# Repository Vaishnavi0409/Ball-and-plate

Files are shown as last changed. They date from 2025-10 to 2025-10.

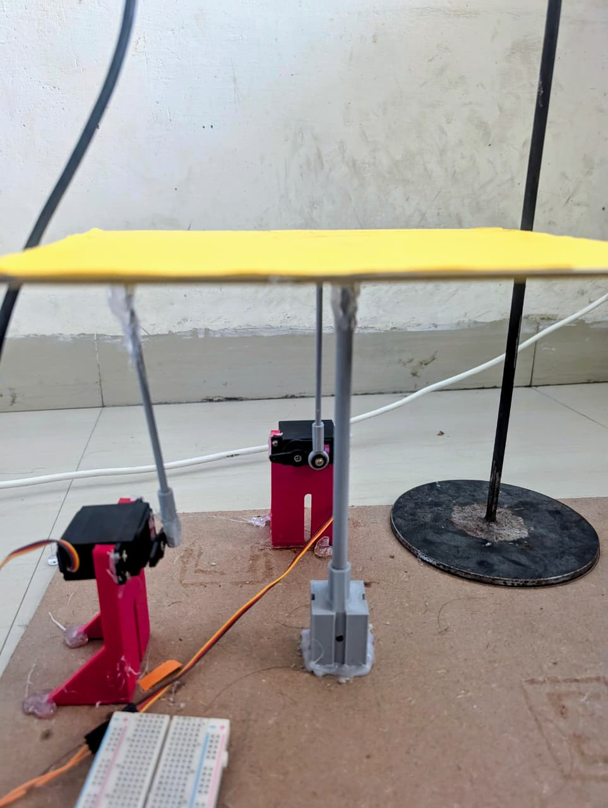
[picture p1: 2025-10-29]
images_video/system_image.jpeg

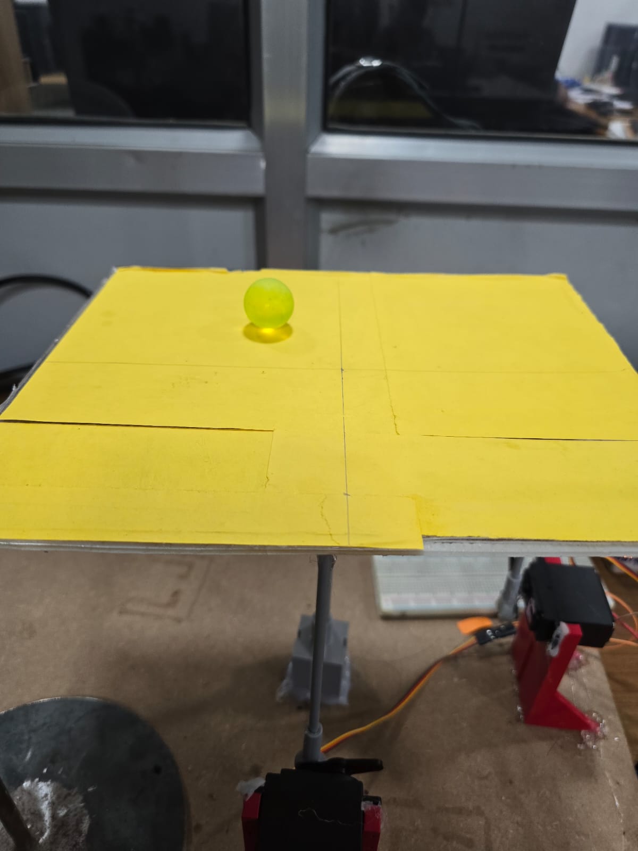
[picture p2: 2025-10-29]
images_video/system image.jpeg

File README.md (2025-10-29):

# Ball and Plate Balancing System
This project is a real-time, closed-loop control system that uses computer vision to balance a ball on a 2-axis tilting plate. The system can also guide the ball to follow dynamic paths, such as a circle or an 8-shape, all controlled via a custom Python GUI.

Initial simulations for the control logic were performed in MATLAB & Simulink (see MATLAB_Simulink folder). The physical model was constructed using custom 3D-printed components.

🎥 Demonstration
The video below shows the ball successfully tracking a circular setpoint (red dot) generated by the GUI.

(Pro Tip: Convert your circle_video.mp4 to a demo.gif to embed it here. You can't embed videos directly, but a GIF will auto-play.)

System Demo

⚙️ Technical Workflow
The system operates in a continuous "see-think-act" loop:

1. Plate Detection (Region of Interest)
To focus processing power and eliminate noise, the system first isolates the plate:

Edge Detection: A first pass is done to identify rectangular shapes in the camera feed.

Color Filtering: The selection is refined by searching for a specific yellow color, locking onto the plate.

Cropping: The video feed is then trimmed to the plate's dimensions (with a 2-pixel offset), creating a precise Region of Interest (ROI).

2. Ball Detection (3-Filter Pipeline)
A robust, 3-stage filter is used to accurately detect the ball within the ROI:

Hough Circle Transform: Detects all circular objects.

Color Filter: Isolates the objects that match the ball's specific color.

Shape & Size Validation: A final filter ensures the object is perfectly round and within the expected size range, rejecting any "absurd" circles or visual noise.

3. PID Control Loop
Error Calculation: Once the ball's (x,y) position is found, the system calculates the error vector (distance) between the ball and the target setpoint (the blue dot).

PID Controller: This error is fed into a PID controller. The controller's output (the corrective tilt angles) is calculated based on the gains (Kpx, Kpy, Kix, Kiy, Kdx, Kdy) set in the GUI.

Serial Communication: The calculated X and Y tilt angles are sent to the Arduino via serial communication at a fixed baud rate.

4. Hardware Actuation
The Arduino, running the final_arduino.py logic, receives the target angles.

It translates these angles into the precise angular positions required for the two servo motors.

The servos tilt the plate, which moves the ball, thus closing the loop.

🚀 Key Features
Real-time PID Control: All P, I, and D gains for both X and Y axes can be tuned live via the GUI for optimal performance.

Dynamic Path Following: Includes modes for "Circle Movement" and "8-Shape Movement," where the setpoint moves and the ball dynamically follows.

Robust 2-Stage Plate Detection: Uses both shape and color to lock onto the plate and create a processing-efficient ROI.

High-Accuracy 3-Filter Ball Tracking: Drastically reduces false positives by filtering for shape, color, and size.

3D-Printed Hardware: The majority of the mechanical components are 3D-printed.

Initial Simulation: Includes MATLAB/Simulink files for reference, showing the initial design and testing of the control theory.

📂 File Structure
🛠️ Hardware & Software
Required Hardware
Arduino (or compatible microcontroller)

2x Servo Motors

USB Webcam

3D-Printed components

A yellow-colored plate

A distinctly colored ball

Software Setup
Python Environment: This project requires Python 3. You can install the necessary libraries using pip:

Arduino Setup:

Upload the code from final_arduino.py to your Arduino board.

Ensure the baud rate in the script matches the one set in interface.py.

▶️ How to Run
Assemble the hardware and connect the Arduino to your computer.

Position the webcam directly above the plate for a top-down view.

Run the main Python application:

The GUI will open, and the camera feed will start.

Use the GUI to tune the PID gains for stable balancing.

Enable the "Circle Movement" or "8-Shape Movement" modes to test dynamic tracking.

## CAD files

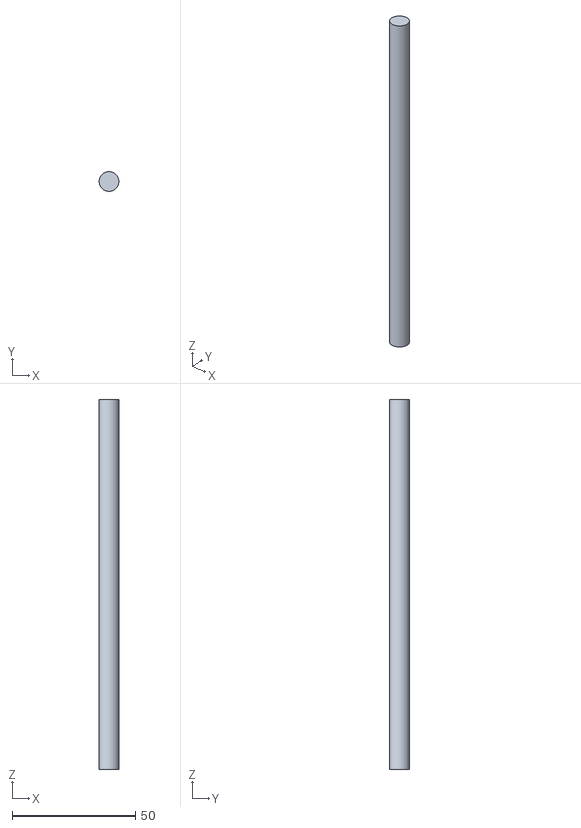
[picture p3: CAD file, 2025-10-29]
CAD/rod_8mm_dia_150mm_len.stl
8.00 x 8.00 x 150.0

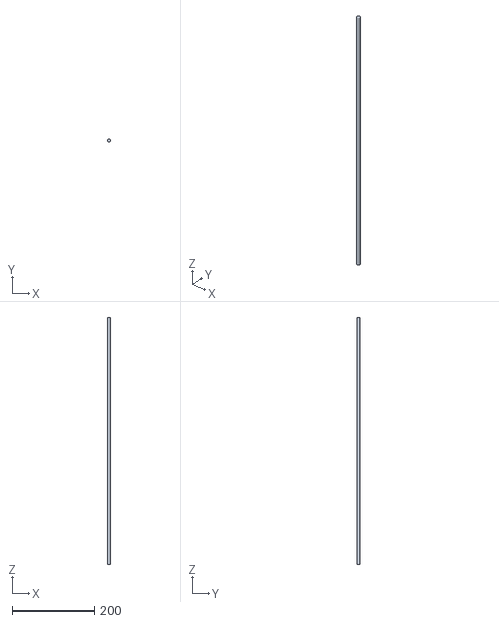
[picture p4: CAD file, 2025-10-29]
CAD/rod_8mm_dia_600mm_len.stl
8.00 x 8.00 x 600.0

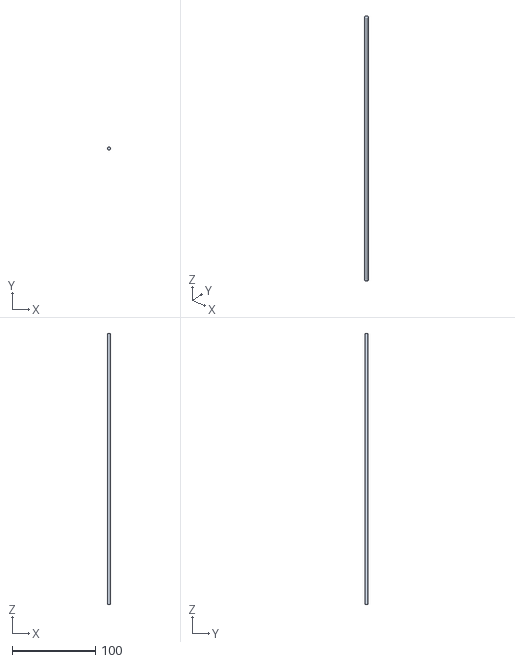
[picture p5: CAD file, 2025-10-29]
CAD/rod_4mm_dia_325mm_len.stl
4.00 x 4.00 x 325.0

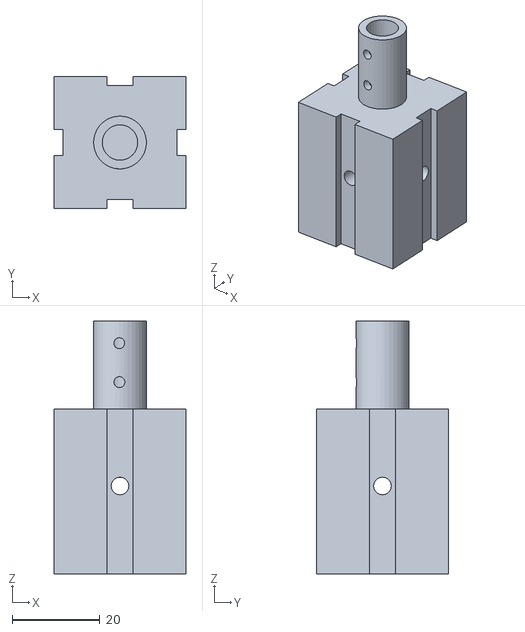
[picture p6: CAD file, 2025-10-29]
CAD/Copy of Camera_Pole_Mount.STL
30.0 x 30.0 x 57.5

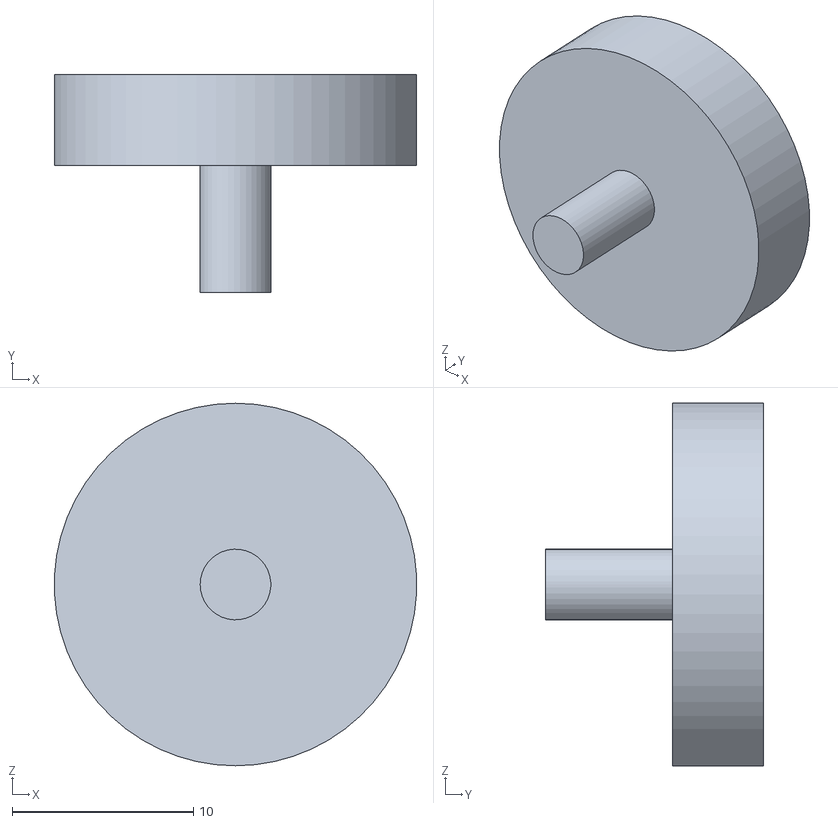
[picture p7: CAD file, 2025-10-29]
CAD/Plug.STL
20.0 x 12.0 x 20.0

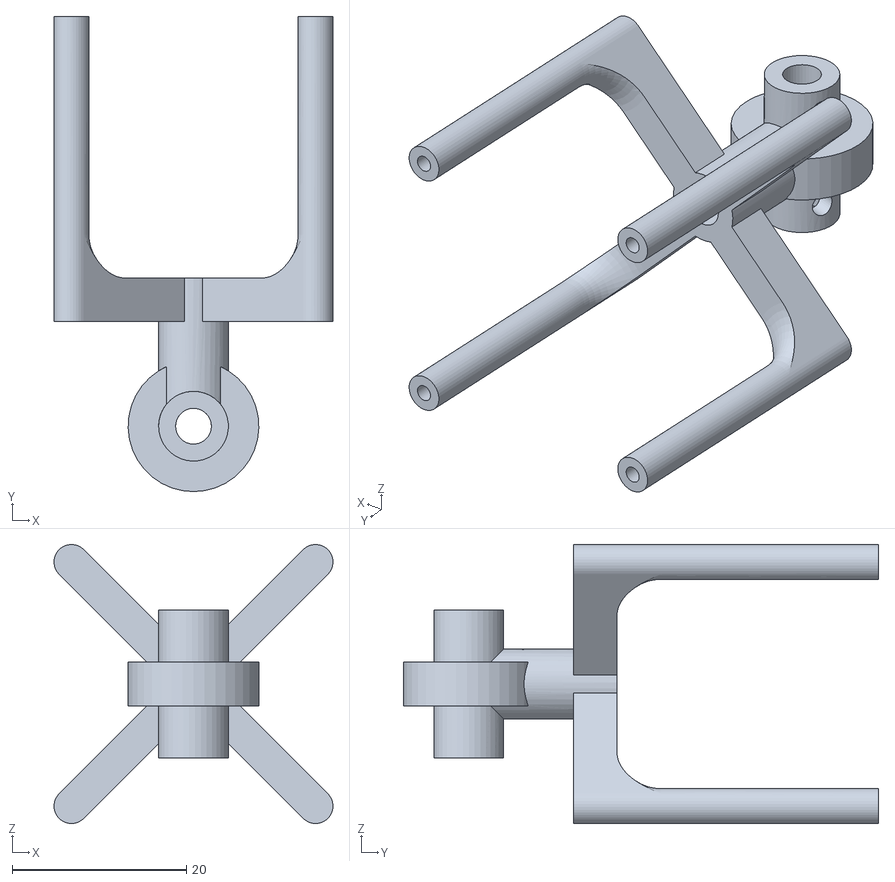
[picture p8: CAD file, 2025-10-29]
CAD/Camera_Slider.STL
32.0 x 54.5 x 32.0

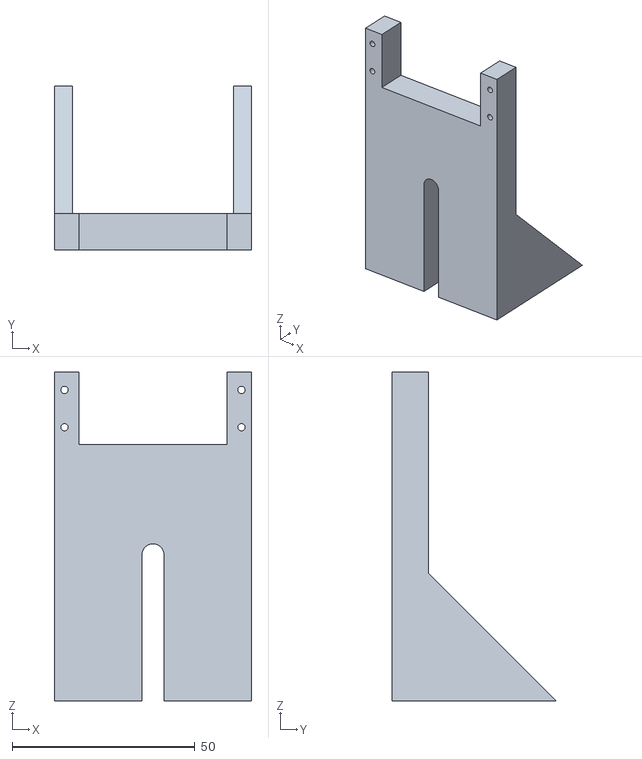
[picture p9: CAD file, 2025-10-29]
CAD/Servo_Mount_1.STL
54.0 x 45.0 x 90.0

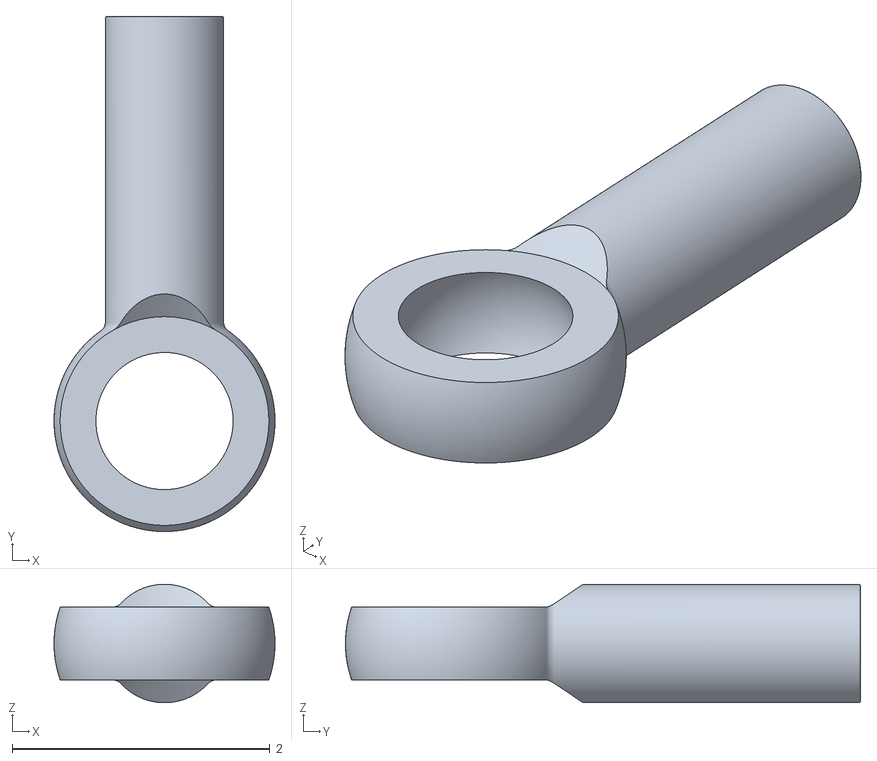
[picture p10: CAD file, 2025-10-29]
CAD/ball_joint.stl
1.72 x 4.00 x 0.92

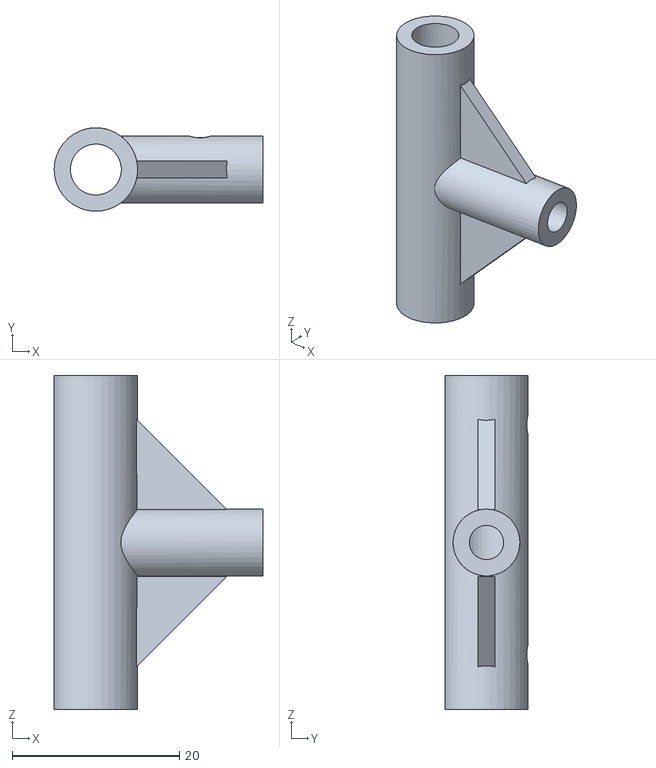
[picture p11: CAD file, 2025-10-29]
CAD/T_Fit.STL
25.0 x 10.00 x 40.0

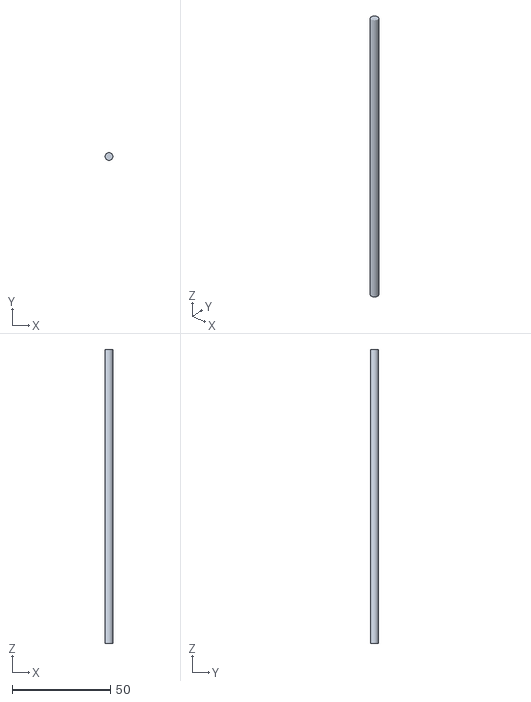
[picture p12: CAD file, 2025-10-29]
CAD/rod_4mm_dia_150mm_len_2piece.stl
4.00 x 4.00 x 150.0

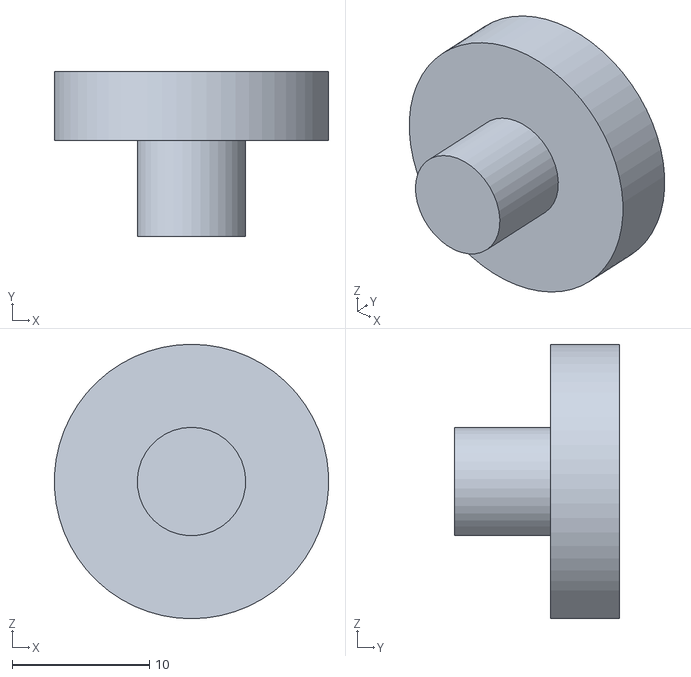
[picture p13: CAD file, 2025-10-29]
CAD/Copy of Part10.STL
20.0 x 12.0 x 20.0

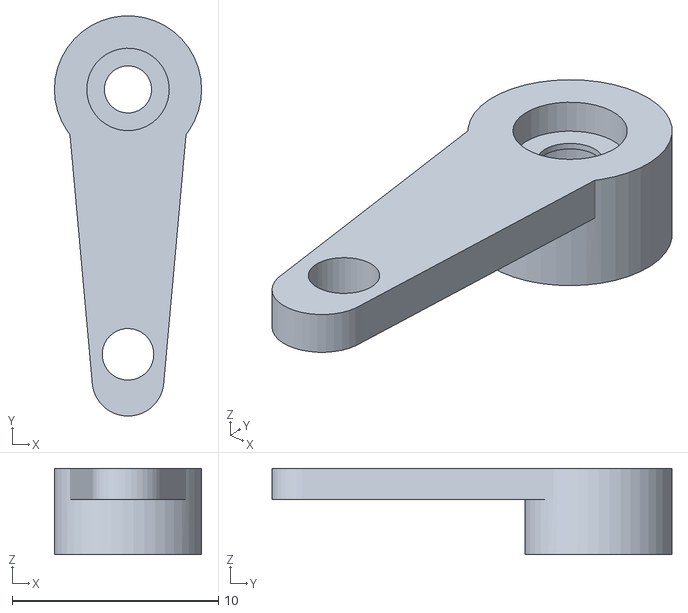
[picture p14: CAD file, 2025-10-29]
CAD/Servo Arm.STL
7.14 x 19.4 x 4.19

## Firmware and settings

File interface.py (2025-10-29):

import time
import cv2
import numpy as np
import serial
from collections import deque
from PID_controller import PIDController 

BOARD_DIMENSIONS = (500, 625)

SERIAL_ENABLED = True

#Constants for visual offset
PIXELS_PER_CM = 15
OFFSET_CM = 1
OFFSET_PX = int(OFFSET_CM * PIXELS_PER_CM)

#Predefined Color Range for the Board (UPDATED TO MATCH IMAGE) 
#These values are derived from the 'Color Tuning' window in the provided image.
LOWER_YELLOW = np.array([7, 63, 121]) 
UPPER_YELLOW = np.array([32, 255, 255]) 


#Initialize PID controllers
pid_x = PIDController(Kp=1.2, Ki=0.05, Kd=0.2, setpoint=(BOARD_DIMENSIONS[0] / 2) + OFFSET_PX)
pid_y = PIDController(Kp=1.2, Ki=0.05, Kd=0.2, setpoint=(BOARD_DIMENSIONS[1] / 2) + OFFSET_PX)


#Temporal smoothing for board corners 
corner_history = deque(maxlen=5)
last_valid_corners = None

#Ball HSV Color Range (will be updated by trackbars) ---
ball_hsv_lower = np.array([25, 0, 80])
ball_hsv_upper = np.array([105, 83, 255])


if SERIAL_ENABLED:
    try:
        ser = serial.Serial('/dev/cu.usbmodem12301', 9600, timeout=1)
        print("Serial connection established")
    except Exception as e:
        print(f"Failed to connect to serial port: {e}")
        SERIAL_ENABLED = False

def nothing(x):
    pass

def update_pid_from_sliders():
    
    pid_x.Kp = cv2.getTrackbarPos("Kp_X", "PID Tuning") / 100.0
    pid_x.Ki = cv2.getTrackbarPos("Ki_X", "PID Tuning") / 1000.0
    pid_x.Kd = cv2.getTrackbarPos("Kd_X", "PID Tuning") / 100.0

    pid_y.Kp = cv2.getTrackbarPos("Kp_Y", "PID Tuning") / 100.0
    pid_y.Ki = cv2.getTrackbarPos("Ki_Y", "PID Tuning") / 1000.0
    pid_y.Kd = cv2.getTrackbarPos("Kd_Y", "PID Tuning") / 100.0

def update_ball_hsv_from_sliders():
    global ball_hsv_lower, ball_hsv_upper
    h_min = cv2.getTrackbarPos("H_min_ball", "PID Tuning")
    s_min = cv2.getTrackbarPos("S_min_ball", "PID Tuning")
    v_min = cv2.getTrackbarPos("V_min_ball", "PID Tuning")
    h_max = cv2.getTrackbarPos("H_max_ball", "PID Tuning")
    s_max = cv2.getTrackbarPos("S_max_ball", "PID Tuning")
    v_max = cv2.getTrackbarPos("V_max_ball", "PID Tuning")
    ball_hsv_lower = np.array([h_min, s_min, v_min])
    ball_hsv_upper = np.array([h_max, s_max, v_max])


def smooth_corners(new_corners):
    """Apply temporal smoothing to corner positions to reduce jitter."""
    global corner_history, last_valid_corners
    
    if new_corners is None:
        return last_valid_corners
    
    corner_history.append(new_corners)
    
    smoothed = np.mean(corner_history, axis=0)
    
    last_valid_corners = smoothed.astype(np.float32)
    return last_valid_corners

def order_points_improved(pts):
    """Order points: top-left, top-right, bottom-right, bottom-left"""
    pts = pts.astype(np.float32)
    center = np.mean(pts, axis=0)

    rect = np.zeros((4, 2), dtype=np.float32)
    top_pts = pts[pts[:, 1] < center[1]]
    bottom_pts = pts[pts[:, 1] >= center[1]]

    if len(top_pts) == 2 and len(bottom_pts) == 2:
        top_sorted = top_pts[np.argsort(top_pts[:, 0])]
        bottom_sorted = bottom_pts[np.argsort(bottom_pts[:, 0])]
        rect[0], rect[1], rect[2], rect[3] = top_sorted[0], top_sorted[1], bottom_sorted[1], bottom_sorted[0]
    else:
        s = pts.sum(axis=1)
        diff = np.diff(pts, axis=1)
        rect[0], rect[2], rect[1], rect[3] = pts[np.argmin(s)], pts[np.argmax(s)], pts[np.argmin(diff)], pts[np.argmax(diff)]

    return rect

def detect_yellow_board_robust(frame, lower_bound, upper_bound, output_size=BOARD_DIMENSIONS, debug=False):
    if frame is None:
        return None, None, None, None

    original_frame = frame.copy()
    mask = None

    try:
        blurred = cv2.GaussianBlur(frame, (7, 7), 0)
        hsv = cv2.cvtColor(blurred, cv2.COLOR_BGR2HSV)
        
        current_mask = cv2.inRange(hsv, lower_bound, upper_bound)
        
        kernel = cv2.getStructuringElement(cv2.MORPH_ELLIPSE, (9, 9))
        mask = cv2.morphologyEx(current_mask, cv2.MORPH_CLOSE, kernel, iterations=4)
        mask = cv2.morphologyEx(mask, cv2.MORPH_OPEN, kernel, iterations=2)

        contours, _ = cv2.findContours(mask, cv2.RETR_EXTERNAL, cv2.CHAIN_APPROX_SIMPLE)
        
        if not contours:
            return original_frame, None, None, mask
        
        largest_contour = max(contours, key=cv2.contourArea)

        if cv2.contourArea(largest_contour) < 5000:
             return original_frame, None, None, mask

        rect = cv2.minAreaRect(largest_contour)
        box = cv2.boxPoints(rect)
        raw_corners = order_points_improved(box).astype(np.float32)
        
        corners = smooth_corners(raw_corners)
        
        if corners is None:
            return original_frame, None, None, mask
        
        out_w, out_h = output_size
        expanded_w, expanded_h = out_w + 2 * OFFSET_PX, out_h + 2 * OFFSET_PX
        dst = np.array([
            [OFFSET_PX, OFFSET_PX], [out_w - 1 + OFFSET_PX, OFFSET_PX],
            [out_w - 1 + OFFSET_PX, out_h - 1 + OFFSET_PX], [OFFSET_PX, out_h - 1 + OFFSET_PX]
        ], dtype=np.float32)

        M = cv2.getPerspectiveTransform(corners, dst)
        warped = cv2.warpPerspective(original_frame, M, (expanded_w, expanded_h), 
                                     flags=cv2.INTER_LINEAR, borderMode=cv2.BORDER_CONSTANT, borderValue=(0, 0, 0))
        return warped, corners, None, mask
    except Exception as e:
        return original_frame, None, None, mask

def detect_yellow_board_with_validation(frame, lower_bound, upper_bound, output_size=BOARD_DIMENSIONS):
    if frame is None: return frame, None, None
    warped, corners, _, mask = detect_yellow_board_robust(frame, lower_bound, upper_bound, output_size, debug=False)
    if corners is not None and warped is not None:
        try:
            gray_warped = cv2.cvtColor(warped, cv2.COLOR_BGR2GRAY)
            if cv2.countNonZero(gray_warped) > 0.1 * gray_warped.size:
                return warped, corners, mask
        except Exception as e: print(f"Validation failed: {e}")
    return frame, None, mask

def detect_ball(frame, lower_bound, upper_bound, debug=False):
    """
    Detects the ball using a robust hybrid method: a user-tunable color filter
    followed by a rigid shape (circularity) analysis.
    """
    if frame is None: return None, None, None
    try:
        output_frame = frame.copy()
        
        # 1. Blur and convert to HSV color space
        blurred = cv2.GaussianBlur(frame, (11, 11), 0)
        hsv = cv2.cvtColor(blurred, cv2.COLOR_BGR2HSV)
        
        # 2. Use the HSV range provided by the trackbars
        mask = cv2.inRange(hsv, lower_bound, upper_bound)
        
        # 3. Clean the mask to remove noise
        mask = cv2.erode(mask, None, iterations=2)
        mask = cv2.dilate(mask, None, iterations=2)
        
        # Show the mask for debugging
        cv2.imshow("Ball Mask", mask)

        # 4. Find contours in the cleaned mask
        contours, _ = cv2.findContours(mask, cv2.RETR_EXTERNAL, cv2.CHAIN_APPROX_SIMPLE)
        
        best_candidate = None
        best_circularity = 0
        
        if contours:
            for cnt in contours:
                # 5. Apply a strict area filter
                area = cv2.contourArea(cnt)
                if not (300 < area < 15000):
                    continue

                # 6. Calculate circularity
                perimeter = cv2.arcLength(cnt, True)
                if perimeter == 0:
                    continue
                
                circularity = 4 * np.pi * (area / (perimeter * perimeter))
                
                # 7. Only consider highly circular contours (relaxed slightly to 0.75)
                if circularity > 0.75:
                    if circularity > best_circularity:
                        ((x, y), radius) = cv2.minEnclosingCircle(cnt)
                        best_circularity = circularity
                        best_candidate = ((int(x), int(y)), int(radius))

        ball_center, ball_radius = best_candidate if best_candidate else (None, None)
        
        # Draw the target (blue dot) at the center of the board
        center_x, center_y = output_frame.shape[1] // 2, output_frame.shape[0] // 2
        cv2.circle(output_frame, (center_x, center_y), 8, (255, 100, 0), -1)
        
        return output_frame, ball_center, ball_radius
    except Exception as e:
        print(f"Ball detection error: {e}")
        return frame, None, None


def ball_position_pid(ball_center, frame_shape, pid_x, pid_y, dt=0.033):
    """Apply PID control to ball position"""
    control_x, control_y = 0.0, 0.0
    if ball_center and dt > 0:
        x, y = ball_center
        control_x, control_y = pid_x.update(x, dt), pid_y.update(y, dt)
        control_x, control_y = max(-100, min(100, control_x)), max(-100, min(100, control_y))
    return control_x, control_y

def calculate_circular_setpoint(start_time, board_shape):
    """Calculates the target (x, y) point for the ball to trace a circle."""
    center_x = (board_shape[0] / 2) + OFFSET_PX
    center_y = (board_shape[1] / 2) + OFFSET_PX
    RADIUS = 140  
    SPEED = 0.2   

    elapsed_time = time.time() - start_time
    angle = elapsed_time * SPEED * 2 * np.pi

    target_x = center_x + RADIUS * np.cos(angle)
    target_y = center_y + RADIUS * np.sin(angle)

    return int(target_x), int(target_y)

def calculate_figure_eight_setpoint(start_time, board_shape):
    """Calculates the target (x, y) point for the ball to trace a figure-eight."""
    center_x = (board_shape[0] / 2) + OFFSET_PX
    center_y = (board_shape[1] / 2) + OFFSET_PX
    RADIUS_X = 140  
    RADIUS_Y = 180  
    SPEED = 0.15

    elapsed_time = time.time() - start_time
    angle = elapsed_time * SPEED * np.pi

    # Parametric equations for a Lissajous curve shaped like a figure-eight
    target_x = center_x + RADIUS_X * np.cos(angle)
    target_y = center_y + RADIUS_Y * np.sin(2 * angle)

    return int(target_x), int(target_y)

def main():
    global last_valid_corners

    cap = cv2.VideoCapture(0)
    # Give the camera time to initialize
    time.sleep(1.0) 
    
    if not cap.isOpened():
        print("Error: Could not open video stream.")
        print("Please check the following:")
        print("1. Is the camera connected and turned on?")
        print("2. Is another application (e.g., Photo Booth, Zoom) using the camera?")
        print("3. On macOS, has the terminal been granted camera permissions?")
        print("4. Try changing cv2.VideoCapture(0) to cv2.VideoCapture(1) or higher.")
        return
        
    cap.set(cv2.CAP_PROP_FRAME_WIDTH, 640)
    cap.set(cv2.CAP_PROP_FRAME_HEIGHT, 480)
    cap.set(cv2.CAP_PROP_BUFFERSIZE, 1)

    cv2.namedWindow("PID Tuning")
    cv2.createTrackbar("Kp_X", "PID Tuning", 80, 500, nothing)
    cv2.createTrackbar("Ki_X", "PID Tuning", 80, 100, nothing)
    cv2.createTrackbar("Kd_X", "PID Tuning", 25, 200, nothing)
    cv2.createTrackbar("Kp_Y", "PID Tuning", 80, 500, nothing)
    cv2.createTrackbar("Ki_Y", "PID Tuning", 80, 100, nothing)
    cv2.createTrackbar("Kd_Y", "PID Tuning", 25, 200, nothing)
    cv2.createTrackbar("Circle Mode", "PID Tuning", 0, 1, nothing)
    cv2.createTrackbar("Figure 8 Mode", "PID Tuning", 0, 1, nothing)

    # Ball HSV Color Tuning Controls
    cv2.createTrackbar("H_min_ball", "PID Tuning", 25, 179, nothing)
    cv2.createTrackbar("S_min_ball", "PID Tuning", 0, 255, nothing)
    cv2.createTrackbar("V_min_ball", "PID Tuning", 80, 255, nothing)
    cv2.createTrackbar("H_max_ball", "PID Tuning", 105, 179, nothing)
    cv2.createTrackbar("S_max_ball", "PID Tuning", 83, 255, nothing)
    cv2.createTrackbar("V_max_ball", "PID Tuning", 255, 255, nothing)


    last_time = time.time()
    last_print_time = time.time()
    circle_mode_start_time = 0
    figure_eight_mode_start_time = 0 
    
    print("Starting ball tracking system...")

    while cap.isOpened():
        ret, frame = cap.read()
        if not ret: 
            print("Error: Could not read frame. Exiting.")
            break
            
        now, dt = time.time(), time.time() - last_time
        last_time = now

        cropped_frame, corners, board_mask = detect_yellow_board_with_validation(frame, LOWER_YELLOW, UPPER_YELLOW)
        
        display_frame = frame.copy()
        if corners is not None:
            cv2.polylines(display_frame, [corners.astype(int)], True, (0, 255, 255), 2, cv2.LINE_AA)
        cv2.imshow('Original Frame', display_frame)
        if board_mask is not None: cv2.imshow("Board Mask", board_mask)

        if cropped_frame is not None:
            cv2.imshow('Warped Board', cropped_frame)
        else:
            expanded_w, expanded_h = BOARD_DIMENSIONS[0] + 2 * OFFSET_PX, BOARD_DIMENSIONS[1] + 2 * OFFSET_PX
            cv2.imshow('Warped Board', np.zeros((expanded_h, expanded_w, 3), dtype=np.uint8))

        update_pid_from_sliders()
        update_ball_hsv_from_sliders()

        balled_frame, final_ball_pos, ball_radius = detect_ball(cropped_frame, ball_hsv_lower, ball_hsv_upper)

        circle_mode_on = cv2.getTrackbarPos("Circle Mode", "PID Tuning") == 1
        figure_eight_mode_on = cv2.getTrackbarPos("Figure 8 Mode", "PID Tuning") == 1
        
        
        if figure_eight_mode_on:
            if figure_eight_mode_start_time == 0:
                figure_eight_mode_start_time = time.time()
            circle_mode_start_time = 0  

            target_x, target_y = calculate_figure_eight_setpoint(figure_eight_mode_start_time, BOARD_DIMENSIONS)
            pid_x.setpoint = target_x
            pid_y.setpoint = target_y
            
            if balled_frame is not None:
                 cv2.circle(balled_frame, (target_x, target_y), 10, (255, 0, 255), 2) 

        elif circle_mode_on:
            if circle_mode_start_time == 0:
                circle_mode_start_time = time.time()
            figure_eight_mode_start_time = 0 
            
            target_x, target_y = calculate_circular_setpoint(circle_mode_start_time, BOARD_DIMENSIONS)
            pid_x.setpoint = target_x
            pid_y.setpoint = target_y
            
            if balled_frame is not None:
                 cv2.circle(balled_frame, (target_x, target_y), 10, (0, 0, 255), 2) 

        else:
           
            circle_mode_start_time = 0
            figure_eight_mode_start_time = 0
            pid_x.setpoint = (BOARD_DIMENSIONS[0] / 2) + OFFSET_PX
            pid_y.setpoint = (BOARD_DIMENSIONS[1] / 2) + OFFSET_PX

        # Unified PID control logic
        control_x, control_y = 0, 0
        distance_from_center = None

        if final_ball_pos:
            control_x, control_y = ball_position_pid(final_ball_pos, BOARD_DIMENSIONS, pid_x, pid_y, max(dt, 0.001))
            # Calculate distance from the current setpoint (which could be moving)
            current_setpoint = (pid_x.setpoint, pid_y.setpoint)
            distance_from_center = np.linalg.norm(np.array(final_ball_pos) - np.array(current_setpoint))
        else:
            # If the ball is lost, reset the PID to avoid windup
            pid_x.reset()
            pid_y.reset()
        
        NEUTRAL_ANGLE = 90
        MAX_TILT_ANGLE = 30
        servo_angle_x = NEUTRAL_ANGLE + (control_x / 100.0) * MAX_TILT_ANGLE
        servo_angle_y = NEUTRAL_ANGLE + (control_y / 100.0) * MAX_TILT_ANGLE

        servo_angle_x = int(np.clip(servo_angle_x, 0, 180))
        servo_angle_y = int(np.clip(servo_angle_y, 0, 180))
        
        if balled_frame is not None:
            if final_ball_pos:
                cv2.circle(balled_frame, final_ball_pos, ball_radius or 20, (0, 255, 0), 3)
            cv2.imshow('Ball Detection', balled_frame)

        if SERIAL_ENABLED:
            try:
                command = f"<{servo_angle_x},{servo_angle_y}>\n"
                ser.write(command.encode('utf-8'))
            except Exception as e:
                print(f"Serial write error: {e}")

        
        if now - last_print_time > 0.1:
            ball_pos_str = f"({final_ball_pos[0]}, {final_ball_pos[1]})" if final_ball_pos else "Not detected"
            dist_str = f"{distance_from_center:.2f}" if distance_from_center is not None else "N/A"
            print(f"Ball: {ball_pos_str}, Distance: {dist_str}, Servos: <{servo_angle_x},{servo_angle_y}>")
            last_print_time = now

        key = cv2.waitKey(1) & 0xFF
        if key == ord('q'): break
        elif key == ord('r'):
            pid_x.reset(); pid_y.reset()
            corner_history.clear()
            last_valid_corners = None
            print("\nPID and history reset")

    cap.release()
    cv2.destroyAllWindows()
    if SERIAL_ENABLED and 'ser' in globals() and ser.is_open:
        ser.write(b"<90,90>\n")
        ser.close()
        print("\nSerial connection closed")

if __name__ == "__main__":
    main()

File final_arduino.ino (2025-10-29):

// Include the Servo library
#include <Servo.h>

// Define the pins for the two servo motors
#define SERVO_X_PIN 9
#define SERVO_Y_PIN 10

// Create servo objects to control the servos
Servo servoX;
Servo servoY;

void setup() {
  // Start serial communication at 9600 bits per second
  Serial.begin(9600);
  
  // Attach the servo objects to their respective pins
  servoX.attach(SERVO_X_PIN);
  servoY.attach(SERVO_Y_PIN);
  
  // Initialize the servos to the neutral (level) position
  servoX.write(90);
  servoY.write(90);
  
  Serial.println("Arduino ready to receive servo angles.");
}

void loop() {
  // Check if data is available to read from the serial port
  if (Serial.available() > 0) {
    // Read the incoming string from Python until a newline character is found
    String data = Serial.readStringUntil('\n');
    
    // Check if the received data is in the expected format (e.g., "<95,88>")
    if (data.startsWith("<") && data.endsWith(">")) {
      
      // Remove the start and end markers
      data = data.substring(1, data.length() - 1);
      
      // Find the comma that separates the two angle values
      int commaIndex = data.indexOf(',');
      
      // Extract the string for the X angle and the Y angle
      String angleX_str = data.substring(0, commaIndex);
      String angleY_str = data.substring(commaIndex + 1);
      
      // Convert the angle strings to integersgive
      int angleX = angleX_str.toInt();
      int angleY = angleY_str.toInt();
      
      // Constrain the values to a safe range (0-180) to prevent servo damage
      angleX = constrain(angleX, 0, 180);
      angleY = constrain(angleY, 0, 180);
      
      // Write the final angles to the servos
      servoX.write(angleX);
      servoY.write(angleY);
    }
  }
}

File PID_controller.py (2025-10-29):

class PIDController:
    def __init__(self, Kp=1.0, Ki=0.0, Kd=0.0, setpoint=0.0,
                 output_limits=(-90, 90), integral_limits=(-100, 100)):
        self.Kp = Kp
        self.Ki = Ki
        self.Kd = Kd
        self.setpoint = setpoint

        self.output_limits = output_limits      # (min, max) for output
        self.integral_limits = integral_limits  # (min, max) for integral term

        self.integral = 0.0
        self.prev_error = 0.0
        self.prev_measurement = None  # needed for derivative-on-measurement

    def update(self, measurement, dt=1.0):
        error = self.setpoint - measurement

        # --- Proportional ---
        P = self.Kp * error

        # --- Integral with clamping (anti-windup) ---
        self.integral += error * dt
        self.integral = max(min(self.integral, self.integral_limits[1]),
                            self.integral_limits[0])
        I = self.Ki * self.integral

        # --- Derivative on measurement ---
        if self.prev_measurement is not None and dt > 0:
            derivative = -(measurement - self.prev_measurement) / dt
        else:
            derivative = 0.0
        D = self.Kd * derivative

        # --- PID output ---
        control = P + I + D

        # --- Output limiting ---
        min_out, max_out = self.output_limits
        control = max(min(control, max_out), min_out)

        # --- Save states ---
        self.prev_error = error
        self.prev_measurement = measurement

        return control

    def reset(self):
        self.integral = 0.0
        self.prev_error = 0.0
        self.prev_measurement = None
